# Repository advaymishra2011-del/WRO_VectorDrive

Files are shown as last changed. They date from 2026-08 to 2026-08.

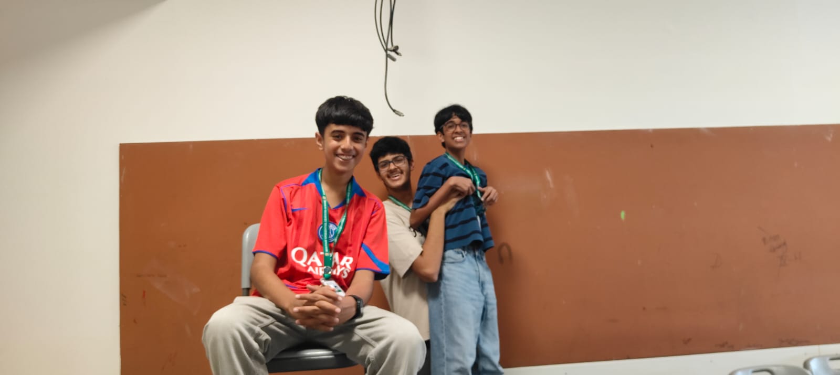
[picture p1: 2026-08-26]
t-photos/Teamphotofunny.JPG

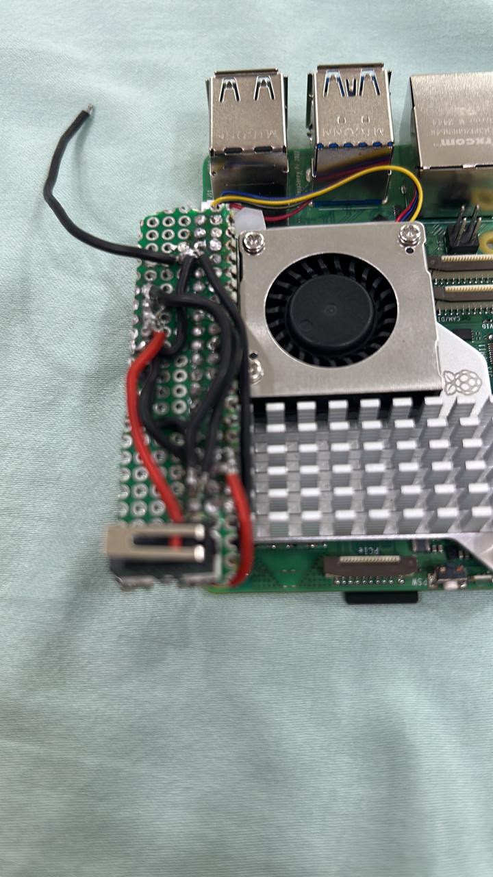
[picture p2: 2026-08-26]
v-photos/WhatsApp Image 2026-08-26 at 16.10.15.jpeg

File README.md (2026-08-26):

# Vector Drive
Documentation for team Vector Drive for WRO Future Engineers 2026

### The Team
**Members**: Kush Agarwal, Shourya Pushkarna, Advay Mishra

## Bot Overview
### How the bot works

**5-ToF system**: 
- 1 Front and 2 on both sides to view full ground and run basic PID to prevent wall collision
- 2 Rear on both ends but facing backwards: Assist while parallel parking and allow to (1) Align with the wall and (2) Measure accurate distance when making a pivot turn in parallel park and making up for innacurate measurement from one
  
**Touch Sensor**:
- Touch sensor on front and back both ends to see collision based on physical touch and prevent damage with wall collision
  
**Other driving components**:
- BNO085: IMU for perfect steering and making desired angles based on obstacles (Colour blocks)
- N20 300RPM motor: Can bear the load and is fast but not too fast such that it may be unncontrollable

### Structure
- Compact chasis structure and built to be small yet powerful: Just 11x10cm but storing 300+g of electronics components such as Pi5 for high speed processing
- Box like, built around battery size
- Simple parallel-ackerman style steering and spur gear rear wheel drive to minimize space and not overcomplicate it

**- Power Management**
- Dual Buck Converter System
- To ensure electrical stability and clean power delivery across high-performance components, the bot implements two separate 5V, 3A Buck Converters
- Isolation: The two converters are completely independent and not connected to each other.Load Splitting: One buck converter is dedicated entirely to powering the Raspberry Pi 5, preventing sudden voltage drops or blackouts during intensive computational tasks. The second converter runs the pico, isolating them from digital noise and current spikes.

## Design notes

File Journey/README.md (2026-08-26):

Imagine the look of surprise on our faces when we walked into the lab and found that our carefully designed Ackermann prints had been replaced by a pair of tiny white Jordans sitting on the print bed.

That was just one of the many unexpected moments in our WRO preparation. Our journey was anything but a straight line. It was filled with failed prints, stubborn hardware, late nights, last-minute fixes, and small victories that made the entire build worth it.

It all started with design. We spent countless late nights in Fusion, iterating through chassis models, tweaking mounts, adjusting tolerances, and redesigning parts that looked perfect on screen but didn't quite fit once they were printed. Every change meant re-exporting, re-printing, and testing again. It was slow and frustrating at times, but it taught us one of the most important lessons of the build: designing for the real world is very different from designing on a screen.

Then came the hardware problems. Our BNO sensor gave us inconsistent I2C readings, with addresses sometimes refusing to appear as expected. We rewired, retested, scanned, and debugged until we finally got stable data. Even our PCB testing turned into a mystery: while checking the circuit with a multimeter, the DRV motor driver showed a faint, ghostly green light despite there being no measurable current where we expected it. Moments like that meant going back to basics, questioning every connection, and testing everything again.

Our Raspberry Pis were another story altogether. The Pi 5 came dangerously close to disaster when a RoboSports friend accidentally connected it to a battery charger, while the Pi 5 fan also ended up getting fried. On top of that, our Pis behaved inconsistently, sometimes working perfectly and sometimes refusing to cooperate for reasons that seemed impossible to find.

And then, just hours before our flight, we discovered that our PCB still wasn't working as expected. With almost no time left, we improvised, using jumper wires directly on the board to bypass faulty connections and keep testing. It wasn't the clean solution we had planned, but it kept the bot alive when we needed it most.

Looking back, WRO preparation wasn't really about building a perfect robot. It was about learning how to keep going when nothing works the way you expect. From stolen print beds and failed tolerances to mysterious sensors, glowing motor drivers, unreliable Pis, fried hardware, and last-minute fixes, every problem became part of the story.

Whether or not our bot outperforms everyone else, it represents a month of intense focus, problem-solving, teamwork, and application. We gave it everything we had, and somewhere between the failed prints, late nights, and frantic fixes, we built more than a robot. We built an experience we'll never forget.

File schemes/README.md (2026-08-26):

# Electromechanical Schematics
The main wiring diagrams and power distribution of components used

**See Circuit Overview for components and distribution**

## Electronics and Component Selection

The electronics system was designed around three main requirements: real-time autonomous control, reliable sensor perception, and low mass and power consumption. The robot uses a Raspberry Pi 3 as the high-level computing platform and a Raspberry Pi Pico as the low-level controller. This separation allows computationally intensive perception and decision-making to run on the Pi while maintaining reliable, deterministic control of the motor, steering servo, encoder and collision sensors through the Pico.

### Computing and Control

The Raspberry Pi 3 was selected as the main computer because the robot requires real-time camera processing alongside multiple sensor inputs. The Camera Module 3 is used for computer vision, while the five VL53L0X sensors, BNO085 IMU and TCS34725 colour sensor provide additional environmental and vehicle-state information. A Pi Zero 2 W was considered because of its smaller size and lower power consumption, but the Pi 3 provides substantially greater computational headroom for image processing and sensor fusion. We therefore accepted the additional mass and power consumption of the Pi 3 in exchange for greater processing capability and reliability.

The Raspberry Pi Pico is used as a dedicated low-level controller. It controls the DRV8833 motor driver and MG90S steering servo, reads the N20 motor encoder and monitors the four collision switches. This division prevents the Linux operating system on the Pi 3 from directly controlling time-critical functions and allows motor and steering control to remain responsive even while the Pi is processing camera data. Communication between the two computers is performed using UART.

### Drive System

The robot uses a GA12-N20 6 V, 300 RPM geared DC motor with an encoder as its drive motor. The motor was selected because its small size and gearbox provide a suitable compromise between speed, torque and packaging requirements for the compact chassis. The encoder additionally provides feedback about motor rotation, allowing the Pico to measure wheel speed and implement closed-loop control rather than relying only on a predetermined PWM value.

The theoretical linear speed of the robot is determined by v=πDN/60 where D is the wheel diameter and N is the motor speed in RPM. Although the motor is rated at approximately 300 RPM at its nominal voltage, the actual vehicle speed will be lower under load. We therefore intend to determine the optimum operating PWM experimentally by measuring acceleration, maximum stable speed and cornering behaviour rather than simply operating the motor at maximum speed. This allows us to prioritise stable lap completion over maximum theoretical speed.

The motor is controlled using a DRV8833 dual H-bridge motor driver. The driver allows the Pico to control motor direction and speed using PWM while supplying the significantly higher current required by the motor. The DRV8833 was chosen instead of larger motor drivers such as the L298N because it is considerably more compact and efficient, making it better suited to a small autonomous vehicle.

The MG90S metal-geared servo is used for steering. A servo was selected instead of an additional drive motor because it provides direct and repeatable control of the steering angle while remaining compact. The Pico generates the servo PWM signal, allowing steering control to remain independent of the computational workload on the Raspberry Pi.

### Power System

The robot is powered by a 7.4 V nominal, 1500 mAh, 25C 2S LiPo battery. A 2S battery was selected because it provides sufficient energy and current capability while remaining relatively compact and lightweight. Its nominal stored energy is approximately

E=VQ=(7.4)(1.5)=11.1 Wh.

The battery is connected to a regulated 5 V supply, which powers the Raspberry Pi 3, Raspberry Pi Pico and MG90S servo. The same regulated 5 V rail is supplied to the DRV8833 motor driver, allowing the N20 motor to operate at approximately 5 V. Operating the 6 V motor at 5 V provides a conservative operating voltage and reduces the need for an additional motor-voltage regulator, simplifying the power system and reducing weight and wiring.

The power system was designed so that the motor current does not pass through the Raspberry Pi or Pico. The DRV8833 acts as the power interface between the Pico's control signals and the motor.

### Distance Sensing

Five VL53L0X time-of-flight sensors are used for distance measurement. Four are positioned toward the front of the robot and one toward the rear. The four front sensors provide multiple measurements across the robot's field of travel, allowing the robot to estimate its position relative to walls and other objects rather than relying on a single distance measurement. The rear sensor provides information during reversing and rear-boundary interactions.

The VL53L0X sensors communicate using I²C. Since multiple identical VL53L0X sensors normally share the same I²C address, a CJMCU TCA9548A 8-channel I²C multiplexer is used. Each sensor is connected to a separate TCA9548A channel, allowing all five sensors to be independently addressed without modifying their hardware addresses. Only five of the eight available channels are therefore required, leaving additional channels available for future expansion.

### Orientation and Colour Sensing

A BNO085 IMU is included to provide information about the robot's orientation and motion. IMU measurements can complement wheel-encoder and camera data, particularly during turns, allowing the robot to estimate changes in heading and improve the consistency of its movement.

A TCS34725 RGB colour sensor is used as a dedicated colour measurement device. A separate colour sensor was selected rather than relying entirely on the camera because it provides direct RGB measurements with low computational overhead. The camera provides spatial and visual information, while the TCS34725 provides a simple independent colour measurement. This gives the robot multiple sensing methods rather than relying on a single sensor.

### Camera and Computer Vision

The Raspberry Pi Camera Module 3 is the primary visual sensor. It provides the image data required for computer-vision algorithms running on the Raspberry Pi 3. The camera allows the robot to detect and analyse features of the track and surrounding environment that cannot be represented by a single distance measurement.

A suitable 15-pin to 22-pin camera FPC cable is used to connect the Camera Module 3 to the Raspberry Pi 3, since the two devices use different physical connector formats.

### Collision Detection

Four NO/NC/C mechanical touch sensors are used as a supplementary collision-detection system. The switches provide a simple digital indication of physical contact and therefore require very little processing or electrical power.

For collision detection, only the Common (C) and Normally Open (NO) terminals are required. The NC terminal is left unused. Each switch is connected to a Pico GPIO using an internal pull-up resistor, producing a simple HIGH/LOW signal. The four sensors allow the robot to determine approximately which region of the vehicle has made contact and provide a backup mechanism for responding to unexpected physical collisions.

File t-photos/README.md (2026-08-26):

To be found attached (as required)-
Official Team Photo
Non Mandated funny team photo

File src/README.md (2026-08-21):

# Software
**Overview**: 
- Use of PID and ToF assisted navigation to navigate the arena and Camera colour detection to create a good route for the bot
- Touch sensors in front-back left-right in case of collision
- 2 ToF in back to help align with the wall with error correction

## UART - Interconnected
Use of UART communication protocol by wiring TX--RX of Pico and Pi5 to communicate 
- **Pico:** Handles all motor movement and collects touch sensor data
- **Pi5:** Handles the CV and main processing, sending signals to pico to run motors at specific speeds and running the main algorithm

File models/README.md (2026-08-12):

# 3D Models
**Overview**: Small, 11x10cm layer style design

### Bottom Layer
**Front**: Parallel Ackerman Style steering setup controlled with parallel motor control
**Rear**: Simple spur gear from motor to shaft that connects to both wheels
**Wheels**: TPA95 Filament tires and PLA rims custom designed and printed

### Mid-Lower Layer
**Battery**: Battery at center to ensure no divergence of center of mass
**Wiring Space**: Taking advantage of gear mounts and extra space to create small wiring pipes to for the extra overcrowded wires

### Surface
**Mounts**: Touch sensor, ToF and Camera mounts on sides
**Components**: Main perfboard with IMU, Pico, Multiplexer and motor driver
**Pi5**: Mounted above the perfboard to ensure balance and optimize usage of space

## Battery Placement and Wiring
### Battery Placement

The 2S 1500 mAh LiPo battery is positioned near the centre of the chassis.

This was done primarily to keep the centre of mass close to the geometric centre of the robot. Placing the relatively heavy battery at one end would increase the moment of inertia about the opposite end and could produce different handling characteristics when accelerating, braking or turning.

Central battery placement also helps distribute the load between the front and rear axles.

The battery is also positioned low in the chassis, lowering the centre of gravity and reducing the tendency of the robot to become unstable during rapid steering changes.

### Wiring Management

The large number of sensors creates a significant wiring requirement, particularly because the robot contains:

- Five VL53L0X sensors
- BNO085
- TCS34725
- Four collision sensors
- Motor encoder
- Servo
- Motor
- Pi 5
- Pico
- Camera

Instead of allowing these wires to occupy the main interior volume of the robot, small wiring channels are integrated into the chassis around the gear mounts and other unused structural spaces.

This serves two purposes:

It makes the wiring more compact and protected from the drivetrain.
It prevents loose wires from interfering with the steering and gears.

The wiring channels therefore allow the same chassis volume to perform both structural and cable-management functions.

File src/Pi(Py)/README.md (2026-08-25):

# Pi3 Code 
Computer vision and sensor control, the main hub of the bot

## Computer Vision (CV)
Use of openCV library "cv2" in python:
- Creates a mask for red, green and purple detection separately and creates contours
- Uses area to filter for the largest object and returns its coordinates and color
- Flexible and able to handle if no object is seen / only 1 is seen
- If 2 as expected are seen, it figures out which is closest and uses its position to navigate

## Start Switch
gpiozero library is used to directly read no/nc/c type switch and run as soon as pressed

## Initialization
When the bot starts, it instantly detects 2 things:
1. Which direction its supposed to run by checking which side its facing using the wall of the parking -- the direction sets 2 values (1) sign and (2) turndir which govern the turning algorithms
2. Zero for the gyro angle, such that if it is at this angle it is exactly straight

It then runs a tested park algorithm by aligning and turning outwards

## Navigation
Captures multiple frames in hopes of seeing an obstacle and its color
   -> If obstacle doesnt exist, PID to align with the wall and move straight
   -> If obstacle exists, run obstacle algorithm

### Obstacle Algorithm
1. The camera looks for the obstacle of the right color and gives its x position
2. A unique PID algorithm is applied to keep the obstacle at the same x position from the bots POV, creating a perfect line of movement and preventing collision
   - The x position is decided by color
3. After the bot reaches the obstacle, it's ToFs detect where the obstacle is and use a short period of PID to stay at a good distance from it
4. After the obstacle is passed, the bot moves forward a bit to prevent collision from the back side

## Laps
The main loop counts the number of proper turns taken as a tracker to see that when 12 have been taken it is time to park

## Park
1. The bot goes forward to the end of the straight with the parking
2. It uses the gyroscope to move perfectly straight and take a U-Turn towards the parking
3. It moves forward till it finds the purple contour of the parking and uses similar-to-obstacle x coordinate alignment
4. It moves forward till it finds the parking seen by a drop in ToF distance -- it checks this 5 times to prevent false detection and failure to park
5. It then slowly moves forward till it finds the other wall and then takes a tested backward U-Turn manouever to park parallel

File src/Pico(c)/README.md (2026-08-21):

# Pico Code 
Motor controls and steering

## Main Loop
- Via UART, the Pi5 sends a command in the format "C, {motorspeed}, {steeringdeg}, {rotations}". C helps it identify that it is send from  Pi5, and the others get updates in the storage of latest message
  -> The main loop keeps listening for these and uses the simple "moveMotor" and "simpleMoveMotor" to turn the motor
- The Pico also keeps listening for touch sensor changes and sends them to the Pi5 in format "T, 0,0,1,1" (e.g.)

## N20 Encoder Motor
- If rotation is None, then the motor simply turns on and off via the function "simpleMoveMotor"
- If rotation is not None, then "moveMotor(speed, rot)" is run which uses a tick system to count rotations
  -> The code is in a sort of "sleep" while the motor is running the given no. of rotations as it waits for the rotation to finish so it can do some other task
  -> In case it is needed by the Pi5, the Pico also sends a message as "D" when the rotations are complete, signaling "You can run further code now"

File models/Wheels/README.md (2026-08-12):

## Wheels
The wheels consist of custom-designed PLA rims with TPA95 filament tyres.

This approach allows the wheel dimensions, tyre profile and hub geometry to be modified specifically for the chassis rather than relying on commercially available wheels.

The compliant TPA95 tyre provides greater grip than a rigid printed wheel and helps absorb small irregularities in the track. The PLA rim provides a lightweight and rigid structure for mounting the tyre and connecting it to the axle.

The wheel diameter is also an important parameter because it directly affects vehicle speed: v=πDN/60 where D is wheel diameter and N is motor RPM.

Therefore, the wheel dimensions were selected together with the 300 RPM N20 motor rather than independently.

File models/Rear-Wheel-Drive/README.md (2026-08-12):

## Rear Wheel Drive
The rear wheels are driven by a single N20 geared motor through a simple spur-gear transmission. A single motor was selected instead of independently driving the two rear wheels because the differential requirement is relatively small for the compact vehicle and the simpler drivetrain reduces:
- Weight,
- Electrical Complexity
- Number of motors
- Number of motor drivers
- Mechanical failure points.

The spur gear transfers the motor's rotation to a common rear axle, allowing both rear wheels to receive drive from the same motor.

The gear ratio can also be adjusted during testing to trade maximum speed for torque and acceleration.

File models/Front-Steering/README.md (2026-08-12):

## Front - Steering
The front wheels use a parallel-Ackermann-style steering mechanism controlled by an MG90S servo. The steering geometry was chosen to provide controlled directional changes while keeping the steering mechanism within the limited width of the chassis.

The use of a mechanical steering linkage allows both front wheels to turn together while maintaining a consistent relationship between their steering angles. This is preferable to independently controlling two steering motors because it reduces the number of actuators, control complexity and occupied space.

The steering servo is positioned so that its movement can be transferred directly to the steering linkage without requiring a large mechanism or additional motor.

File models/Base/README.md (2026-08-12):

## Base
Main base where everything is mounted and electronics will be placed

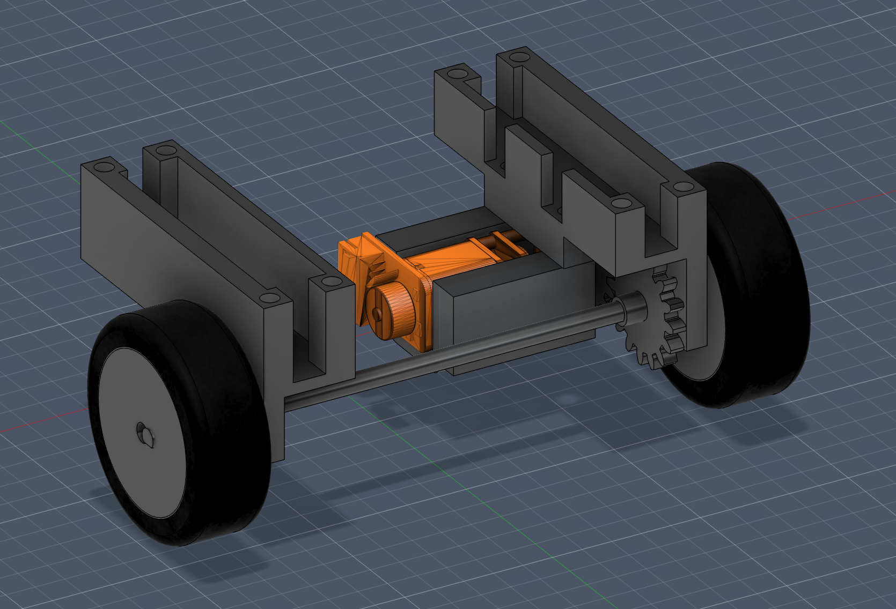
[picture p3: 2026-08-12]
models/Rear-Wheel-Drive/RWD_img.png

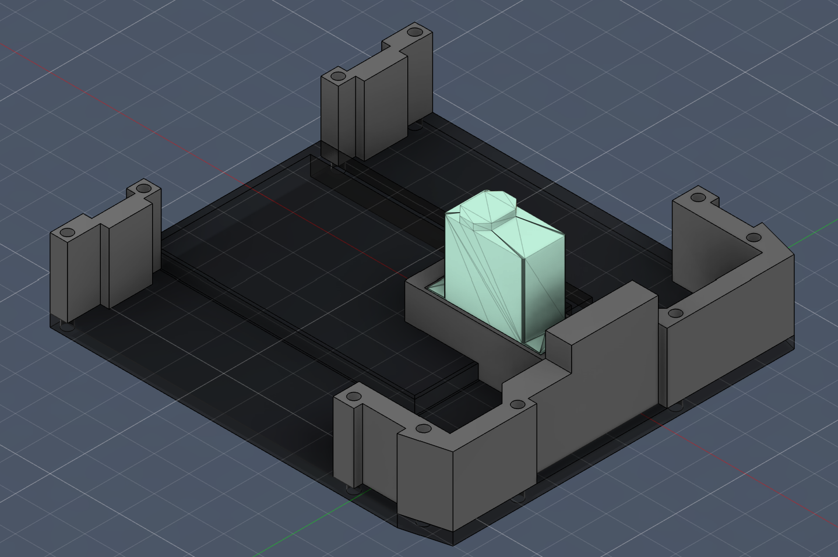
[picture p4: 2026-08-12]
models/Base/Base_img.png

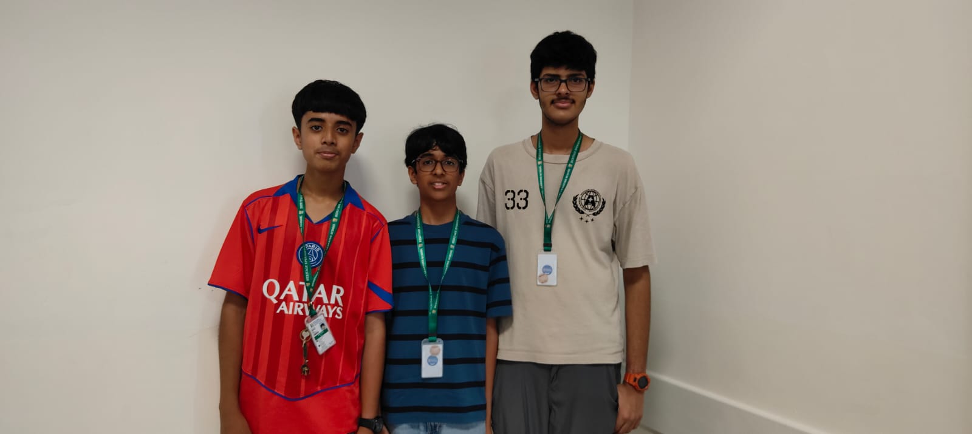
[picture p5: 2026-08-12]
t-photos/Team-Photo_Official.jpeg

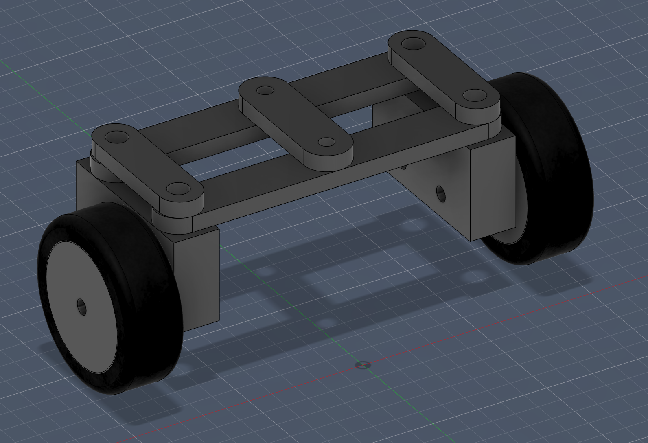
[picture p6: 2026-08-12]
models/Front-Steering/FW_img.png

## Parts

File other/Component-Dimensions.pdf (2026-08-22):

S.No | Component | Dimensions
1 | CJMCU TCA9548A I2C 8 Channel Multiple Extensions Development Board | 31x21mm
2 | Pro- Range 7.4V 1500mAh 25C 2S Lithium Polymer Battery Pack | 74 x 34 x 17 mm
3 | GA12-N20 6V 300RPM Micro DC Reducer Motor Encoder with Wire | 24x10x11mm
4 | NO NC C Touch sensor | 11x4mm
5 | BNO085 IMU Sensor Module | 26x27mm
6 | Raspberry Pi Pico Camera Module 3 | 25x24mm
7 | CJMCU-34725 TCS34725 Color Sensor RGB Module | 21x21mm
Arducam B0087 15 Pin 1.0mm Pitch to 22 Pin 0.5mm Camera Cable for Raspberry Pi Zero Version 1.3 Specific 8
10 | MG90S 9g Servo Metal Gear - 180 Degree
11 | DRV8833 Motor Driver | 18x21mm
12 | VL53L0X ToF x5 (1 back, 4 front) | 15x12mm

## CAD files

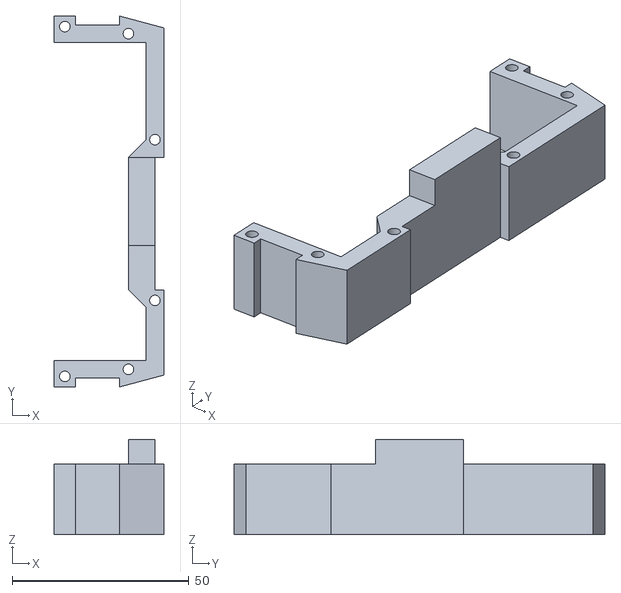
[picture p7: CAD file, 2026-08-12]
models/Base/Front-Main-Mount.stl
31.0 x 105.0 x 27.0

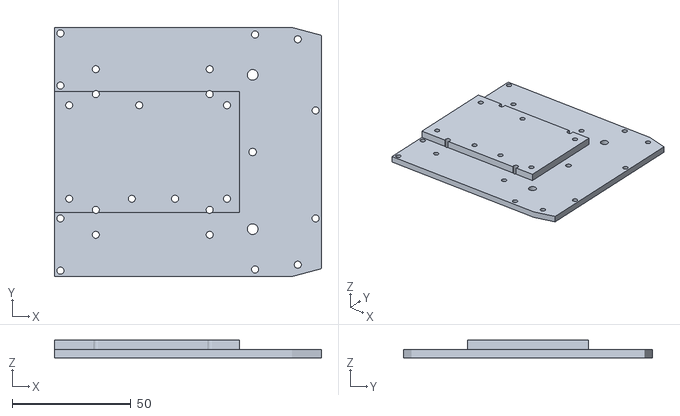
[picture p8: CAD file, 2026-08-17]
models/Base/Basev2.stl
112.5 x 105.0 x 7.50

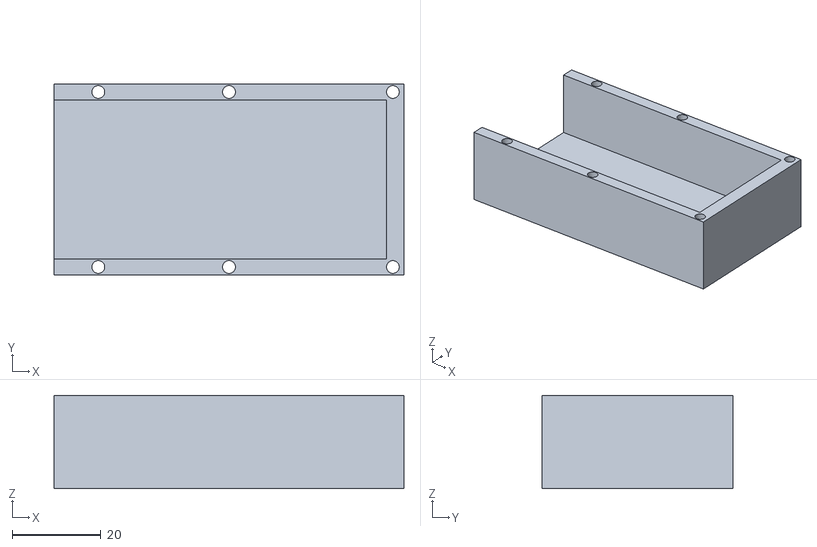
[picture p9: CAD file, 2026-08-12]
models/BatteryMount.stl
79.0 x 43.0 x 21.0

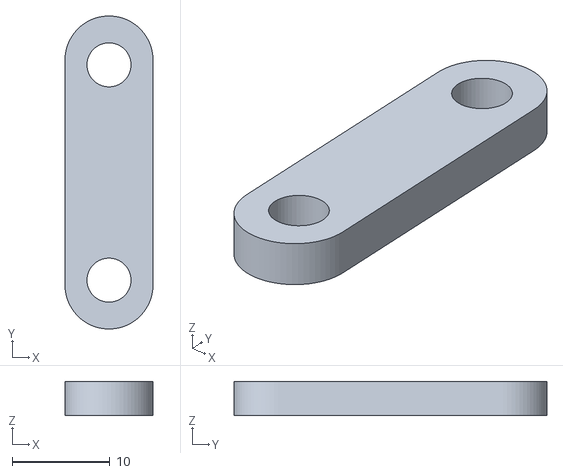
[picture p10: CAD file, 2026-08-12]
models/Front-Steering/Bar2(Small,bh).stl
9.00 x 32.0 x 3.50

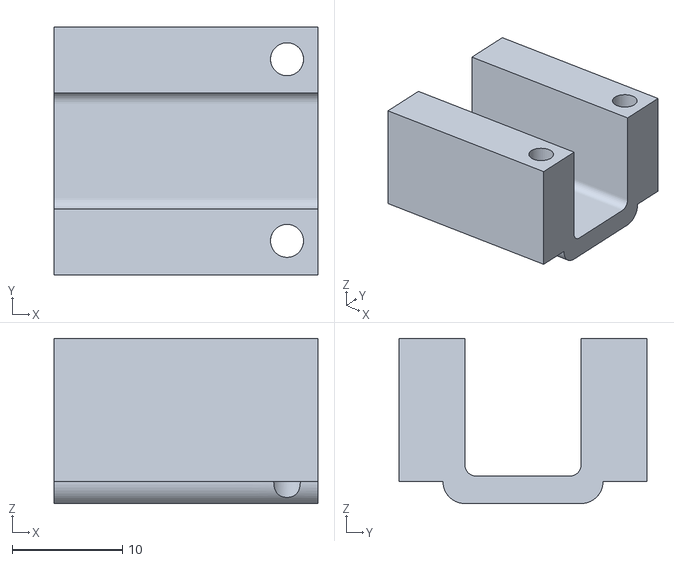
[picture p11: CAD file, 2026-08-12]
models/Rear-Wheel-Drive/MotorMount.stl
24.0 x 22.5 x 15.0

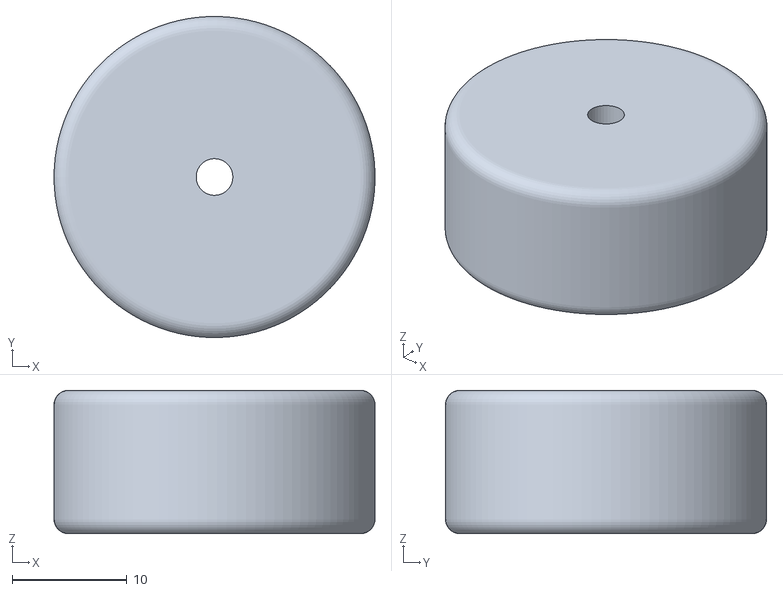
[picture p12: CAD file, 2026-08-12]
models/Wheels/Rim(Type1).stl
28.0 x 28.0 x 12.5

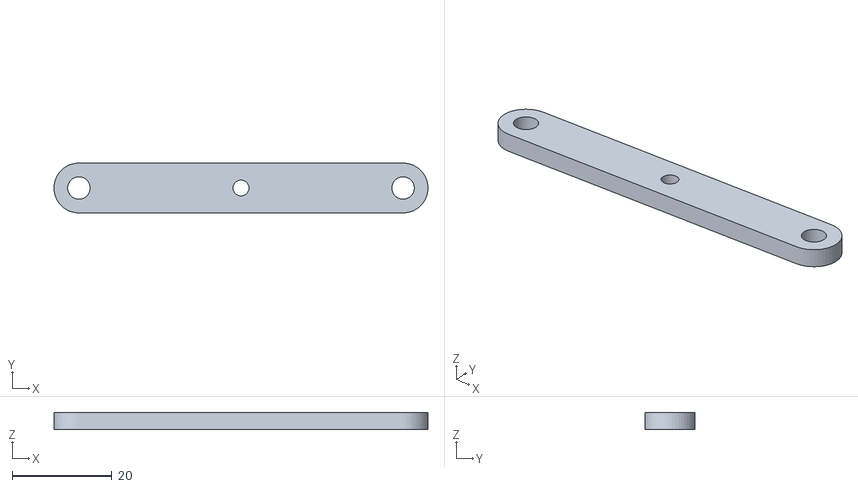
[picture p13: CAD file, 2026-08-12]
models/Front-Steering/Bar1(Long).stl
75.0 x 10.0 x 3.50

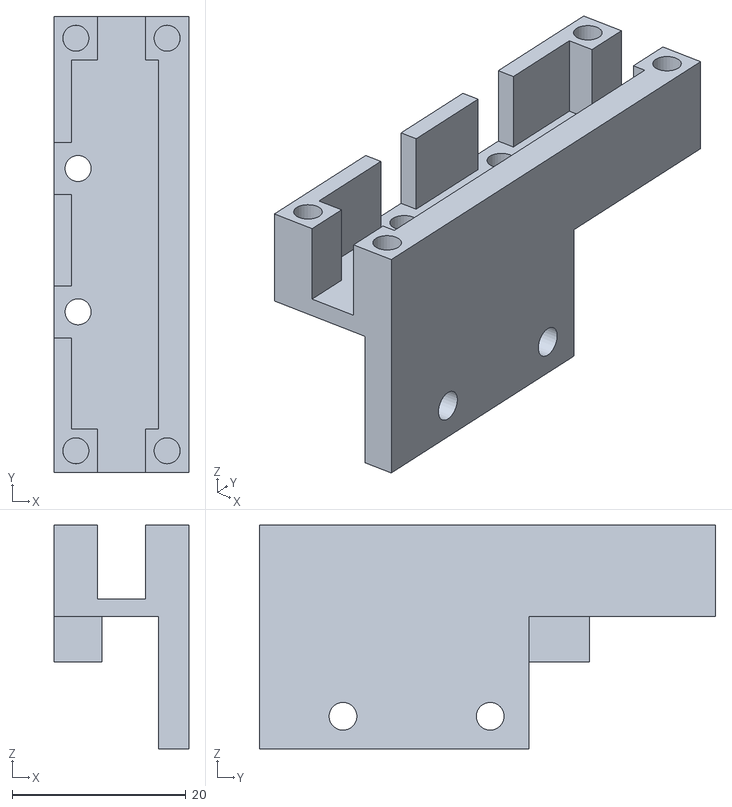
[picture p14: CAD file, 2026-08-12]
models/Rear-Wheel-Drive/WheelSupport(Gear-Side).stl
15.5 x 52.5 x 25.8

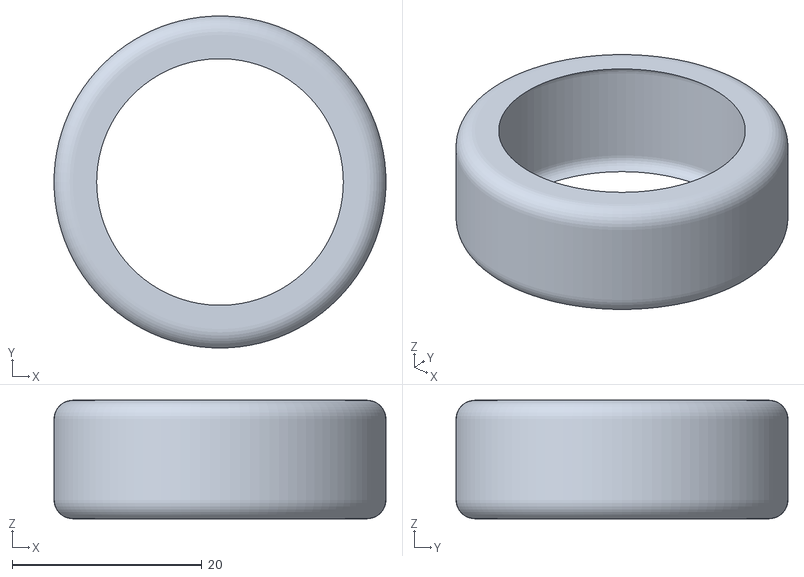
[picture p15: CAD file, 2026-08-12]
models/Wheels/Tyre(TPA).stl
35.0 x 35.0 x 12.5

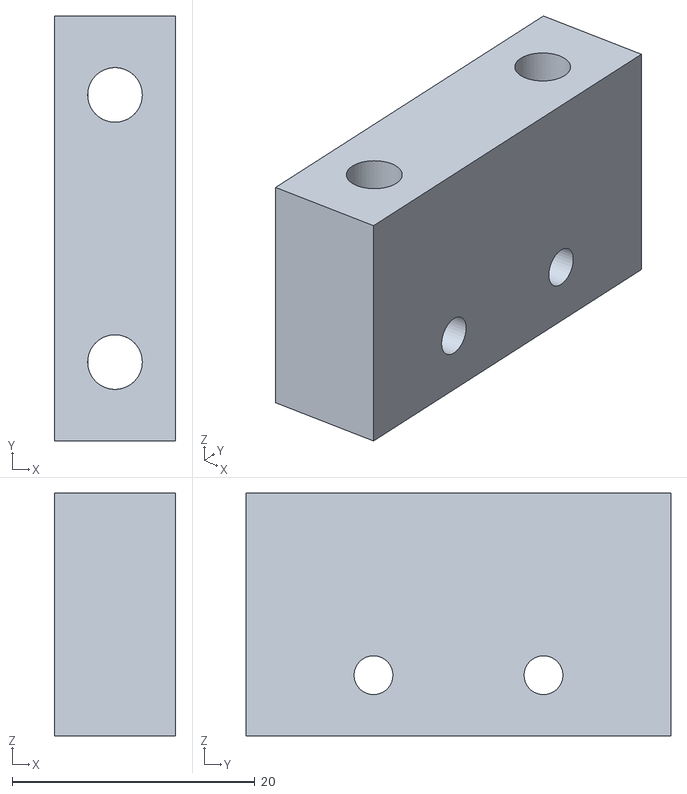
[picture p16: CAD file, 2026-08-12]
models/Front-Steering/Front_Wheel-mount.stl
10.0 x 35.0 x 20.0

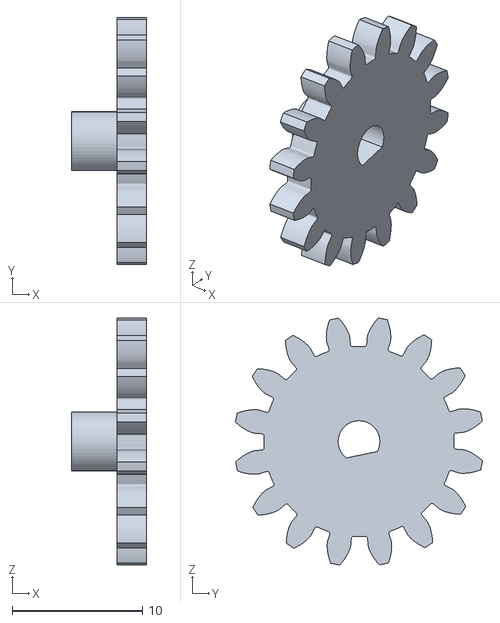
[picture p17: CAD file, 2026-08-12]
models/Rear-Wheel-Drive/Gear(Spur,x2).stl
5.74 x 19.0 x 19.0

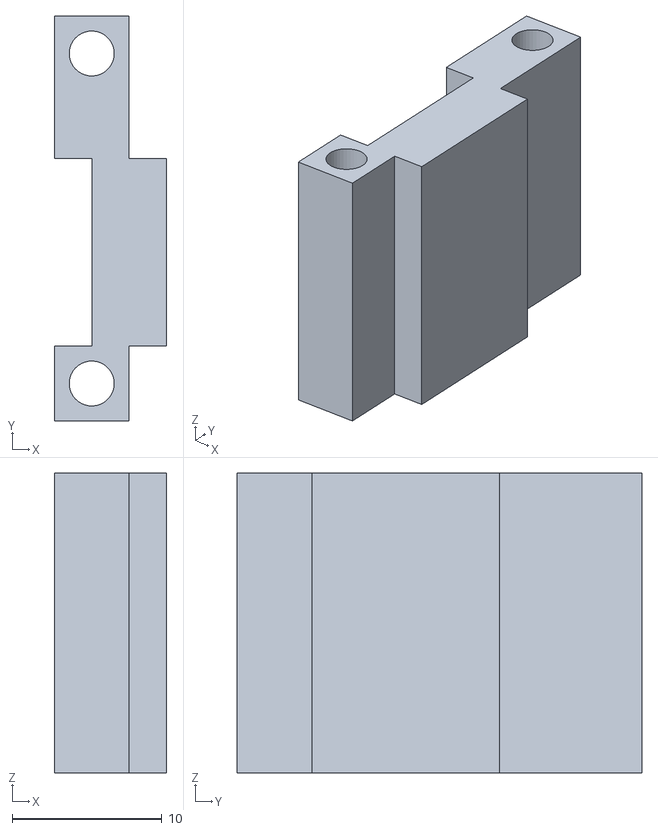
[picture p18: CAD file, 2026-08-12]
models/Base/Back-ToF-Mount(Left).stl
7.50 x 27.0 x 20.0

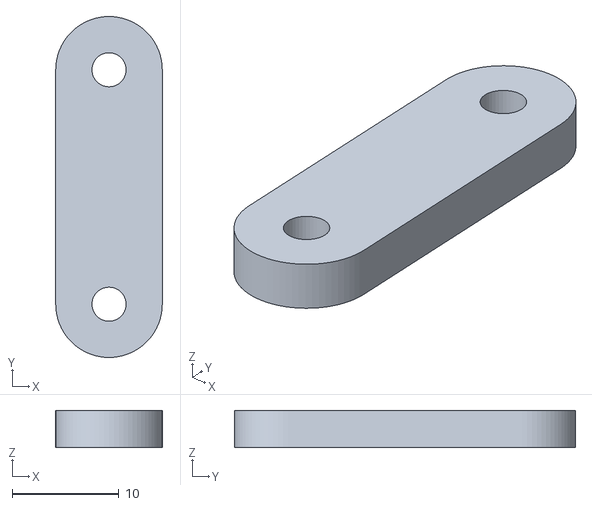
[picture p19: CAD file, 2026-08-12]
models/Front-Steering/Bar3(Small,sh).stl
10.0 x 32.0 x 3.50

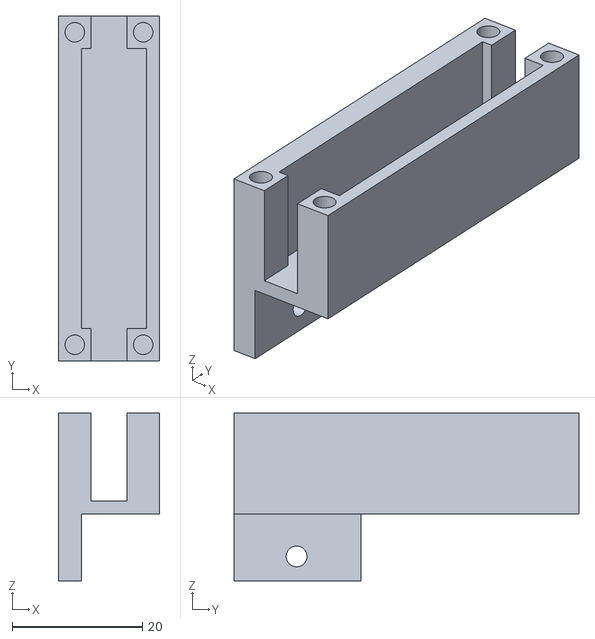
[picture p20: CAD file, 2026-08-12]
models/Rear-Wheel-Drive/WheelSupport(Empty-Side).stl
15.5 x 53.0 x 25.8

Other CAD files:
models/Base/Basev1.stl
models/Wheels/Rim(Type2).stl
models/Base/Servo-Mount.stl
models/Rear-Wheel-Drive/Shaft(Rear).stl
models/Base/Back-ToF-Mount(Right).stl

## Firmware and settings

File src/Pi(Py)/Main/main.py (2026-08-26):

from Main.Algorithms import *
import statistics

turn = 75
large_buffer = 100
bufpark = 4

def getDirection():
    direction = None
    while direction is None:
        dataleft = []
        dataright = []
        for i in range(5):
            dataleft.append(getDistances(tofs)["left"])
            dataright.append(getDistances(tofs)["right"])
        lef = statistics.mean(dataleft)
        rig = statistics.mean(dataright)

        if lef<rig:
            direction = "clockwise"
        elif rig<lef:
            direction = "counterclockwise"
        else: direction = None

    distances = getDistances(tofs)
    lef1 = distances["left"]
    rig1 = distances["right"]
    while(lef1 == rig1):
        distances = getDistances(tofs)
        lef1 = distances["left"]
        rig1 = distances["right"]
        if lef1<rig1:
            direction = "clockwise"
        elif rig1<lef1:
            direction = "counterclockwise"
    return direction

def captureFrame():
    data = []
    for i in range(5):
        frame = get_frame()
        img = cv(frame)
        if img:
            if img[0] is not None:
                color = img[0]["color"]
            if color is not None: 
                data.append(color)
            
        time.sleep(0.01)
    if not data: return None
    mode = statistics.mode(data)
    return mode

def obstacleMain(tofs, val3, speed, val, sign, turndir):
    tracker = True
    counter = 0
    while tracker:
        color = captureFrame()
        if color is None: 
            while True:
                startPid(tofs, 20, turndir, val)
                
                time.sleep(0.1)

                if captureFrame() is not None: break
                if getDistances(tofs)[turndir]   >= large_buffer:
                    tracker = False
                    stopPid()
                    break
        else:
            if counter < 2:
                obstacleAvoidance(tofs, val3, speed, val, color)
                counter += 1
            else: pass
            if getDistances(tofs)[turndir]   >= large_buffer: tracker = False
                
    turn(200, sign*25, sign*75)
    return

front_buffer = 7

def parkAlign(tofs, val3, speed, val, sign, turndir, gz_0):
    tracker = True
    counter = 0
    while tracker:
        color = captureFrame()
        if color is None: 
            while True:
                startPid(tofs, 10, turndir, val)
                
                time.sleep(0.1)

                if captureFrame() is not None: break
                if getDistances(tofs)[turndir]   >= large_buffer:
                    tracker = False
                    stopPid()
                    break
        else:
            if counter < 1:
                obstacleAvoidance(tofs, val3, speed, val, color)
                counter += 1
            else: pass
            if getDistances(tofs)[turndir]   >= large_buffer: tracker = False

    gyroPid(gz_0, 200, val4, 15)
    turn(175, sign*(-30), sign*(-180))
    frame = get_frame()
    if detect_parking(frame) is None: gyroPid(gz_0, 175, val4, None, 1)
    else: 
        parking_detected = False
        state = {
                "integral": 0,
                "last_error": 0,
                "last_time": time.monotonic()
        }
        while not parking_detected:
            frame = get_frame()
            cx = detect_parking(frame)

            distances = getDistances(tofs)
            front = distances["front"]
            main = distances[turndir]

            

            if turndir == "left":
                fake = [
                    {"color": "GREEN", "cx":cx}
                ]
                
                if cx is not None: pidcx(val3, cx, 175, "GREEN", fake, state)

                elif front <= front_buffer or receiveData()[touch_front_right] == 1:
                    interrupt("left")

            if turndir == "right":
                fake = [
                    {"color": "RED", "cx":cx}
                ]
                
                if cx is not None: pidcx(val3, cx, 175, "RED", fake, state)

                elif front <= front_buffer or receiveData()[touch_front_left] == 1:
                    interrupt("right")

            if main <= bufpark:
                sendCommand(0, 0)
                data = []
                for i in range(5):
                    data.append(getDistances(tofs)[main])
                mean = statistics.mean(data)
                if mean <= bufpark: 
                    park(turndir, sign)


def park(turndir, sign):
    stage = 1
    while True:
        dist = getDistances(tofs)[turndir]

        if dist is None: continue

        if stage == 1:
            startPid(tofs, 3, turndir, val, 125)

            if dist >= 18:
                stopPid()
                stage = 2

        elif stage == 2:
            startPid(tofs, 23, turndir, val, 150)

            if dist <= 3:
                stopPid()
                stage = 3

        elif stage == 3:
            startPid(tofs, 3, turndir, val, 125)

            if dist >= 18:
                stopPid()
                gyroPid(getRot(), 150, val4, None, 4)
                turn(-200, sign*30, sign*(-180))
                wallAlign(tofs, 3, val2, 4)
            break
        time.sleep(0.01)
    return

#=========================START BUTTON==============================
from gpiozero import Button

switch = Button(5)

#=========================================================================
#==================================MAIN===================================
#=========================================================================
switch.wait_for_press()
print("Starting...")
Run = True
while Run:
    gz_0 = getRot()
    direction = getDirection()
    if(direction == "clockwise"):
        sign = 1
        turndir = "right"
    elif(direction == "counterclockwise"):
        sign = -1
        turndir = "left"

    #Exit parking
    wallAlign(tofs, 3, val2, 4)
    turn(150, sign*30, sign*90)
    turn(150, sign*(-1)*30, sign*(-1)*turn)

    for i in range(12):
        obstacleMain(tofs, val3, 200, val, sign, turndir)

    #Parallel park
    parkAlign(tofs, val3, 200, val, sign, turndir, gz_0)

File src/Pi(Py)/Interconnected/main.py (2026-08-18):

import time
import cv2
from flask import config
import numpy as np
import serial
import board
import busio
from picamera2 import Picamera2

from Camera.CVcam import get_frame, cv
from Pico import sendCommand, receiveData
from Sensing.ToF import getDistances
from Sensing.IMU import getRot
from Sensing.TCS import getColor

#-------------------------------------------------------CV CONFIG-------------------------------------------------------
# 2. Optimized HSV Boundaries (Tweak based on your room's light)
LOWER_GREEN = np.array([35, 60, 60])
UPPER_GREEN = np.array([85, 255, 255])

# Red spans across the HSV 0/180 boundary
LOWER_RED1, UPPER_RED1 = np.array([0, 70, 70]), np.array([10, 255, 255])
LOWER_RED2, UPPER_RED2 = np.array([170, 70, 70]), np.array([180, 255, 255])

RESOLUTION = (640, 480)

kernel = np.ones((3, 3), np.uint8)

picam2 = Picamera2()

config = picam2.create_video_configuration(
    main={"size": RESOLUTION, "format": "RGB888"}
)

picam2.configure(config)
picam2.start()  # Initialize the camera configuration


#-----------------------------------------------------SENSOR SETUP-----------------------------------------------------
#================BNO===========================
from adafruit_bno08x.i2c import BNO08X_I2C

from adafruit_bno08x import (
    BNO_REPORT_ACCELEROMETER,
    BNO_REPORT_GYROSCOPE,
    BNO_REPORT_MAGNETOMETER,
    BNO_REPORT_ROTATION_VECTOR
)

i2c = busio.I2C(
    board.SCL,
    board.SDA,
    frequency=400000
)

bno = BNO08X_I2C(i2c)

bno.enable_feature(BNO_REPORT_ACCELEROMETER)
bno.enable_feature(BNO_REPORT_GYROSCOPE)
bno.enable_feature(BNO_REPORT_MAGNETOMETER)
bno.enable_feature(BNO_REPORT_ROTATION_VECTOR)

#================================PICO===========================
pico = serial.Serial(
    #"/dev/ttyAMA0", Check on pi
    115200,
    timeout=0.1
)

#================================TCS===============================
import adafruit_tcs34725

i2c = board.I2C()

tcs = adafruit_tcs34725.TCS34725(i2c)


#=================================ToF=============================
import adafruit_tca9548a
import adafruit_vl53l0x

# Main Pi I²C bus
i2c = board.I2C()

# TCA9548A multiplexer
tca = adafruit_tca9548a.TCA9548A(i2c)

# VL53L0X sensors
tofs = {
    "front": adafruit_vl53l0x.VL53L0X(tca[0]),
    "left": adafruit_vl53l0x.VL53L0X(tca[1]),
    "right": adafruit_vl53l0x.VL53L0X(tca[2]),
    "rear_left": adafruit_vl53l0x.VL53L0X(tca[3]),
    "rear_right": adafruit_vl53l0x.VL53L0X(tca[4])
}


#---------------------------------------------MOVEMENT PROTOCOLS--------------------------------------
#==========================BACK ALIGN========================
val2 = [2, 0.01, 0.01]

def mod(x):
    if x<0:
        return -x
    elif x>=0:
        return x
    else:
        return None

def backPID(speed, tofs, val2):
    sendCommand(-100, 0)
    
    distances = getDistances(tofs)
    left = distances["rear_left"]
    right = distances["rear_right"]
    
    if speed<0:
        error = left - right
    elif speed>=0:
        error = right - left
    last_error = error
    integral += error
    derivative = error - last_error

    pid = (val2[0]*error) + (val2[1]*integral) + (val2[2]*derivative)

    sendCommand(-100, pid)
    time.sleep(0.01)

def wallAlign(tofs, dist, val2, buffer):

    distances = getDistances(tofs)
    left = distances["rear_left"]
    right = distances["rear_right"]
    gap = min(left, right)

    
    while(gap>=dist):
        backPID(-100, tofs, val2)

    while mod(left-right) >= buffer:
        for i in range(100):
            backPID(100, tofs, val2)
        for i in range(100):
            backPID(-100, tofs, val2)

#=================================WALL FOLLOW=====================================
import threading

stop_switch = threading.Event()
worker_thread = None

val = [2, 0.01, 0.01]

def loop_worker(switch, tofs, dist, side, val, bno):
    gz = 0
    gz_set = getRot(bno)
    while not switch.is_set():
        sendCommand(200, 0)
        tof = getDistances(tofs)[side]

        if side == "left":
            error = dist - tof
        elif side == "right":
            error = tof - dist

        derivative = error - last_error
        integral += error
        last_error = error

        pid = (val[0]*error)+(val[1]*integral)+(val[2]*derivative)
        if gz < 31:
            sendCommand(200, pid)
        elif gz > 31:
            sendCommand(200, 0)
            time.sleep(0.05)

        gz = mod(getRot(bno) - gz_set)
        
        time.sleep(0.05)  
        


def startPid(tofs, dist, side, val):
    global worker_thread
    if worker_thread and worker_thread.is_alive():
        return
        
    stop_switch.clear()
    worker_thread = threading.Thread(target=loop_worker, args=(stop_switch, tofs, dist, side, val), daemon=True)
    worker_thread.start()


def stopPid():
    global worker_thread
    stop_switch.set()
    if worker_thread:
        worker_thread.join()

#=============================STEER=======================================
def turn(speed, sharpness, deg, bno):
    gz = 0
    gz_set = getRot(bno)
    sendCommand(speed, sharpness)
    while mod(gz) < mod(deg):
        gz = getRot(bno) - gz_set
        time.sleep(0.005)
    sendCommand(0, 0)

    




    
    

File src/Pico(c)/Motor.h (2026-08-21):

const int encoderA = 8;
const int encoderB = 7;
#include <Pi-UART.h>
#include <Steering.h>

const int fwd = 4;
const int bwd = 5;

const int fwdSpeed = 200;
const int bwdSpeed = -100;
const int rotation = 300;
volatile long encoderTicks = 0;

//Touch
const int pin1 = 10;
const int pin2 = 11;
const int pin3 = 12;
const int pin4 = 13;


//------------------MOTOR------------------------------------
void moveMotor(int speed, float rot) {
  long targetTicks = abs(rot*300); //Test
  speed = constrain(speed, -255, 255);
  resetTicks();
  if(speed<0){
    analogWrite(bwd, -speed);
  } else {
    analogWrite(fwd, speed);
  }
  while(getTicks()<=targetTicks){
    //Run main loop code while waiting
    
    receive(current);

    steer(current.steer);

    if (millis() - lastTouchSend >= 30) {
        lastTouchSend = millis();
        touch = {
            digitalRead(pin1) == LOW,
            digitalRead(pin2) == LOW,
            digitalRead(pin3) == LOW,
            digitalRead(pin4) == LOW
        };
        send(touch);
    }

    delay(1);
  }
  serial1.println("D");
}

void simpleMoveMotor(int speed) { 
  speed = constrain(speed, -255, 255);
  if(speed<0){
    analogWrite(bwd, -speed);
  } else {
    analogWrite(fwd, speed);
  }
}


//---------------------ENCODER------------------
void resetTicks() { 
  noInterrupts();
  encoderTicks = 0;
  interrupts();
}

long getTicks() {
  noInterrupts();
  long safe =   encoderTicks;
  interrupts();
  return safe;
}

void readEncoder() {
  if(digitalRead(encoderB)==HIGH){
    encoderTicks++;
  } else {
    encoderTicks--;
  }
}

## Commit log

2026-08-11 Added circuit distribution diagram
2026-08-11 Wiring Diagram added
2026-08-11 Added Circuit Diagram
2026-08-12 Rename Circuit Distrubution to Circuit Overview
2026-08-12 Uploaded Schematics
2026-08-12 Update Circuit Overview
2026-08-12 Enhance README with battery and wiring management info
    Added details about battery placement and wiring management for improved stability and organization.
2026-08-17 Updated Base
    [Basev2.stl]
2026-08-17 UART pico
2026-08-20 Switch added
2026-08-20 UART modification
2026-08-20 UART pico side
2026-08-20 Update README with main loop and motor details
    Added details about the main loop and N20 encoder motor functionality.
2026-08-21 Updated UART
2026-08-22 Update README with improved steering description
    Clarified the description of the steering and drive system.
2026-08-24 Modify circuit overview with updated components
    Updated circuit overview to reflect changes in components.
2026-08-26 Add power management details to README
    Added power management section detailing the dual buck converter system for electrical stability and isolation of components.
